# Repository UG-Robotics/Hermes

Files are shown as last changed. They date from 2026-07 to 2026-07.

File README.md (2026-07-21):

# HERMES - WRO 2026 Future Engineers 

Hermes is an autonomous 1:X model car built for the **World Robot Olympiad
2026 Future Engineers** self-driving challenge. It completes both events on the
3m × 3m field — the **Open Challenge** (three laps of a randomised-wall track)
and the **Obstacle Challenge** (three laps obeying red/green traffic signs, then
a parallel park) — under a single start button, with no human input after the
press.

This repository is the complete engineering record: mechanical CAD
(`models/`), electronics and wiring (`schemes/`, `components/`), the full
robot software (`src/`), and supporting media (`v-photos/`, `t-photos/`,
`video/`). The detailed build write-up is in
[`HERMES_TechnicalDocument_WRO2026.pdf`](HERMES_TechnicalDocument_WRO2026.pdf).

---

## How it works at a glance

Hermes uses a **two-tier compute** split, connected by one UART link:

| Tier | Board | Responsibility |
|---|---|---|
| **High-level autonomy** | Raspberry Pi 4 | camera vision, state machine, planning, control decisions |
| **Low-level real-time** | ESP32 | motor + steering-servo PWM, IMU + dual ToF sensing, start button, telemetry |

The Pi never touches a sensor register directly — every IMU/ToF value arrives
as a telemetry packet from the ESP32, and every drive decision leaves as a
command packet. That clean boundary is what lets the **entire stack run on a
laptop with no robot attached** (simulated ESP32 + synthetic camera) for
development and testing.

**Core hardware:** Raspberry Pi 4 · ESP32 · Pi Camera · LSM6DSO 6-axis IMU ·
2× VL53L1X time-of-flight sensors · N20 gear-motor with L298N driver ·
steering servo (Ackermann) · 18650 Li-ion pack + buck converter. See
[`components/`](components/) and [`schemes/`](schemes/) for parts and wiring.

---

## Challenge strategy

### One button, two challenges (auto-detection)

WRO rules allow only **one** start button, so Hermes can't be *told* which
challenge it's running — it works it out itself. The insight: a **red/green
traffic-sign pillar is unique to the Obstacle Challenge**.

- See a pillar → latch **Obstacle** mode (drive the pass-side + parking logic).
- Complete a **full lap with no pillar** → latch **Open** mode (drop pillar
  perception, bias toward the inner wall, finish by lap count).

### Open Challenge

Drive three laps of the corridor using **camera-based wall centering** trimmed
by an **IMU heading-hold PID**, counting the four orange/blue corner markers per
lap. The colour of the *first* corner marker latches the run **direction**;
Hermes then biases its racing line toward the **inner wall** for a tighter,
safer line. After the third lap it clears the finish line and stops.

### Obstacle Challenge

Same lap-following, plus: each red/green pillar raises an avoidance turn —
**pass right of red, left of green** — executed as a smooth IMU-held heading
change, and capped by the side ToF sensors so clearing a pillar never means
clipping a wall. After three laps it hunts the **magenta parking lot** and runs
a staged **parallel-parking** maneuver.

The full behaviour is a priority-driven state machine
(`INIT → WAIT_FOR_START → FOLLOW_TRACK ⇄ AVOID_OBSTACLE / LAP_CHECK →
FINAL_APPROACH → PARK → STOP`, with `ERROR` fail-safe). Diagram and spec:
[`other/State_Transition_Diagram.png`](other/State_Transition_Diagram.png),
[`other/State_Machine_Spec.pdf`](other/State_Machine_Spec.pdf).

---

## Running the software

All commands run from `src/`. The control loop and simulation need only the
**standard library**; the extras below unlock hardware, the dashboard, and
vision.

```bash
pip install -r requirements.txt      # flask, pyserial, pynput, pillow, numpy
pip install opencv-python            # required for real camera perception

python main.py --mode sim --auto-start   # full stack vs simulated hardware, no robot
python main.py --mode dashboard          # live web UI (telemetry + camera + manual drive)
python main.py --mode test               # unit + integration test suite
python main.py --mode run                # REAL hardware (Pi + ESP32) — the competition entry
```

Manual driving is always available (keyboard `w/a/s/d`, space, `m` to toggle, or
the dashboard controls) as an override. Firmware for the ESP32 lives in
[`src/firmware/esp_controller/`](src/firmware/esp_controller/) (Arduino).

---

## Tuning for competition day

The software is written so that going from "runs" to "wins" is **only constant
tuning** — no code changes. Every threshold, gain, colour range, and maneuver
timing is centralised in [`src/config/`](src/config/), and the step-by-step
on-mat procedure (servo trim, IMU sign, PID, HSV colours, ToF safety, parking
timings, …) is documented in **[`src/CALIBRATION.md`](src/CALIBRATION.md)**.

---

## Repository map

| Path | Contents |
|---|---|
| [`src/`](src/) | All robot software — see [`src/README.md`](src/README.md) for the module-by-module breakdown |
| [`src/config/`](src/config/) | Every tunable constant (camera, PID, thresholds, parking, robot) |
| [`src/firmware/`](src/firmware/) | ESP32 real-time controller firmware |
| [`models/`](models/) | Mechanical CAD (chassis, steering, drivetrain) |
| [`schemes/`](schemes/) | Wiring diagrams and electronics schematics |
| [`components/`](components/) | Bill of materials, datasheets, part photos |
| [`v-photos/`](v-photos/) · [`t-photos/`](t-photos/) | Vehicle and team photos |
| [`video/`](video/) | Performance video links ([`video/README.md`](video/README.md)) |
| [`other/`](other/) | State-machine spec and diagrams |

---

## Software architecture

Layered robotics stack, one direction of data flow, each layer independently
testable:

```
PERCEPTION  →  EVENTS  →  STATE MACHINE  →  PLANNING  →  CONTROL  →  COMMUNICATION  →  ESP32
 (camera)     (typed,     (priority        (lane /      (heading-    (UART packets)    (motor +
              prioritised) transitions)     obstacle /   hold PID +                     servo +
                                            parking)     slew)                          sensors)
```

Perception detects, planning decides, control stabilises, communication
transmits — no layer reaches across another. A live **monitoring dashboard**
(`src/monitoring/`) mirrors the same telemetry the robot runs on, so a run
produces a complete, replayable narrative of every decision. Full rationale and
per-module docs: [`src/README.md`](src/README.md).

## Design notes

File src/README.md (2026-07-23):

# `src/` - Robot Runtime Software

## Overview

This directory contains the complete runtime software stack for the autonomous vehicle used in the WRO Future Engineers competition.

The purpose of this folder is to organize all software required for:

* autonomous navigation
* perception and obstacle detection
* decision-making
* motion planning
* low-level control
* communication with embedded hardware

This directory intentionally contains ONLY software directly related to the operation of the physical robot during runtime.

In practice, that includes the live monitoring dashboard, state-machine logic, testing assets, and the embedded controller firmware alongside the main autonomy loop.

The following are intentionally kept out of the runtime path:

* CAD files
* documentation assets (kept in the repo-root folders)
* temporary experiments

Development-only tooling that *does* live under `src/` is clearly separated
from the runtime stack: `simulation/` (Gazebo world + MATLAB vision notes) and
`testing/` are for the bench, not the competition loop, and nothing in the
autonomy path imports them.

---

# High-Level System Architecture

The software stack follows a layered robotics architecture:

```text
PERCEPTION
    ↓
EVENT GENERATION
    ↓
STATE MACHINE / DECISION LOGIC
    ↓
MOTION PLANNING
    ↓
CONTROL
    ↓
COMMUNICATION
    ↓
MCU → MOTOR + SERVO ACTUATION
```

The Raspberry Pi acts as the high-level autonomy computer:

* computer vision
* state transitions
* planning
* decision-making

The ESP32 acts as the low-level controller:

* PWM generation
* steering actuation
* motor actuation
* real-time control loops

---

# Directory Structure

```text
src/
│
├── main.py                 # CLI entry point / mode dispatcher
├── runtime.py              # the orchestrator: the 20 Hz control loop
│
├── perception/
├── state_machine/
├── planning/
├── control/
├── communication/
├── hardware/
├── monitoring/
├── testing/
├── firmware/
├── simulation/             # Gazebo / MATLAB assets (dev only, not runtime)
├── utils/
└── config/
```

---

# Entry Point

## `main.py`

The thin command-line front door. It parses `--mode` and hardware flags
(`--real` / `--sim`) and hands off to the right runner:

* `run` — real hardware, the competition entry point (default)
* `sim` — the same loop against a simulated ESP32 + synthetic camera
* `dashboard` — launch the live monitoring web UI
* `scenario` — replay a scripted event scenario headless
* `test` — run the unittest suite

`main.py` holds no business logic — it only wires up a `Runtime` (or a
scenario/test runner) and starts it.

## `runtime.py`

The actual orchestrator. `Runtime` builds every subsystem (real or simulated),
then runs one control cycle per tick at ~20 Hz:

```text
ingest ESP32 telemetry (IMU / ToF)      ← _drain_incoming
    ↓
perceive (camera → pillar/lane/corner/parking events)   ← _update_vision
    ↓
update state machine (drain queued events)   ← _drain_events
    ↓
decide drive intent (state → speed/steer/action)   ← _resolve_command
    ↓
IMU heading-hold PID correction
    ↓
send CMD packet to ESP32
    ↓
publish a telemetry snapshot for the dashboard
```

It is also where run-level behaviour lives that isn't any single subsystem's
job: challenge auto-detection (OPEN vs OBSTACLE), lap counting, the start
delay, the open-run finish timer, and driving the parking maneuver. Keep
per-subsystem logic in the modules below; `runtime.py` only coordinates them.

---

# Module Descriptions

---

# `perception/`

Responsible for environmental understanding and sensor interpretation.

This module processes camera and sensor data to generate meaningful observations for the rest of the system.

## Responsibilities

* image acquisition
* preprocessing
* ROI extraction
* track detection
* wall detection
* obstacle detection
* pillar color classification
* finish zone detection

## Example Files

```text
perception/
├── camera.py            # real (Picamera2/OpenCV) + synthetic frame source
├── preprocessing.py     # thin compatibility wrapper over pillar detection
├── roi.py               # region-of-interest crop helpers
├── pillar_detection.py  # red/green traffic-sign pillars + pass-side
├── corner_detection.py  # orange/blue corner markers → lap + direction
└── finish_detection.py  # magenta parking-zone marker
```

## Notes

This module should NOT:

* control motors
* make navigation decisions
* contain PID logic

It only answers:

> “What does the robot currently observe?”

---

# `state_machine/`

Responsible for robot behavioural logic.

This module determines:

* what state the robot is currently in
* when state transitions occur
* how events are prioritized

## Responsibilities

* state tracking
* transition logic
* event handling
* state priority management
* fail-safe behaviour

## Example Files

```text
state_machine/
├── states.py         # the State enum
├── transitions.py    # (state, event) → next state table
├── events.py         # EventType enum + priority map + Event/make_event
├── priorities.py     # Priority levels
├── event_queue.py    # thread-safe priority queue (drain per tick)
├── robot_context.py  # shared run state (laps, direction, challenge_mode, …)
└── manager.py        # applies events, gates INIT on camera/serial readiness
```

## Example States

```text
INIT
WAIT_FOR_START
FOLLOW_TRACK
AVOID_OBSTACLE
LAP_CHECK
FINAL_APPROACH
PARK
STOP
ERROR
```

## Notes

The state machine should only manage behaviour and transitions.

It should NOT:

* process raw camera frames
* directly generate PWM signals

---

# `monitoring/`

Responsible for the live dashboard, scenario runner, and telemetry visualization used during development and testing.

This module mirrors the same telemetry stream used by the robot runtime, so the dashboard and the headless scenario runner always show the current system state.

## Responsibilities

* dashboard UI
* scenario simulation
* telemetry visualization
* manual control hooks
* live log display

## Example Files

```text
monitoring/
├── dashboard.py
├── scenario.py
├── __init__.py
├── scenarios/
└── templates/
```

## Notes

The full module documentation lives in `monitoring/README.md`.

---

# `testing/`

Responsible for automated regression tests and mock event helpers.

This folder keeps verification assets separate from the runtime stack while still documenting the expected behaviour of the major software subsystems.

## Responsibilities

* unit tests
* protocol validation
* state-machine regression coverage
* robot-context checks
* mock event generation

## Example Files

```text
testing/
├── test_drive_command.py
├── test_event_queue.py
├── test_protocol.py
├── test_robot_context.py
├── test_transitions.py
└── mock_events.py
```

---

# `firmware/esp_controller/`

Responsible for the microcontroller firmware that executes low-level motor, servo, and telemetry tasks.

This firmware acts as the bridge between high-level autonomy code and the physical actuators on the robot.

## Responsibilities

* serial protocol handling
* motor control
* servo control
* telemetry reporting
* embedded configuration

## Example Files

```text
firmware/esp_controller/
├── esp_controller.ino
├── config.h
├── motor.cpp
├── motor.h
├── servo_control.cpp
├── servo_control.h
├── serial_protocol.cpp
├── serial_protocol.h
├── telemetry.cpp
├── telemetry.h
└── robot_data.h
```

---

# `planning/`

Responsible for motion-level decision making.

This layer transforms behavioural goals into motion targets.

## Responsibilities

* corridor centering (ToF + IMU)
* obstacle-side planning
* steering target generation
* parking trajectory generation
* path adjustment

## Example Files

```text
planning/
├── wall_centering.py    # ToF-based corridor centering (replaces camera lane centering)
├── obstacle_planner.py
├── trajectory.py
└── parking_planner.py
```

## Notes

This layer answers:

> “Where should the robot move next?”

---

# `control/`

Responsible for low-level motion stabilization and command generation.

This module converts motion targets into stable control outputs.

## Responsibilities

* PID control
* steering smoothing
* speed regulation
* filtering
* actuator command generation

## Example Files

```text
control/
├── pid.py
├── steering_control.py
├── speed_controller.py
└── filters.py
```

## Notes

This module should NOT:

* perform computer vision
* make strategic decisions

It answers:

> “How do we physically achieve the desired motion?”

---

# `communication/`

Responsible for Raspberry Pi ↔ MCU communication.

This layer abstracts the serial communication protocol between the high-level computer and the embedded controller.

## Responsibilities

* serial communication
* packet encoding
* packet decoding
* command validation
* timeout handling

## Example Files

```text
communication/
├── serial_link.py
├── protocol.py
└── packet_parser.py
```

## Wire Protocol

Every line is a self-identifying, comma-delimited packet (see
`protocol.py` / `packet_parser.py`).

Pi → ESP32:

```text
CMD,<speed>,<steer>,<ACTION>,<mode>   e.g. CMD,150,-12,FORWARD,0
EMG,<mode>                            emergency stop (bypasses CMD parsing)
PING                                  liveness check
```

ESP32 → Pi:

```text
TEL,ax,ay,az,gx,gy,gz,tof1_mm,tof2_mm   sensor telemetry (~20 Hz)
STATUS,<message>                        boot / error text
EVT,<name>                              hardware event, e.g. START_BUTTON_PRESSED
ACK[,tag]                               acknowledgement
```

## Notes

Communication failures should trigger safe fail-state behaviour.

---

# `hardware/`

Responsible for hardware abstraction and sensor interfaces.

This layer isolates hardware-specific implementations from higher-level logic.

## Responsibilities

* IMU interface
* TOF sensor interface
* button input handling
* diagnostics
* hardware initialization

## Example Files

```text
hardware/
├── imu.py
├── tof.py
├── buttons.py
└── diagnostics.py
```

## Notes

This layer should expose clean interfaces to the rest of the system.

Higher-level modules should not depend on raw hardware implementation details.

---

# `utils/`

Contains reusable helper utilities used across the project.

## Responsibilities

* logging
* timers
* debugging utilities
* math helper functions
* common reusable helpers

## Example Files

```text
utils/
├── logger.py
├── timers.py
├── math_utils.py
└── debug.py
```

---
#`utils/logger.py`
# Logging System

## Purpose

The logging system provides a consistent way for every subsystem of the robot to report information, warnings, errors, and debugging information during development, simulation, and competition runs.

Examples of information that should be logged include:

* State transitions
* Sensor readings
* Obstacle detections
* Lap completions
* Parking events
* Communication failures
* Runtime errors
* Emergency stops

Using a centralized logger makes debugging significantly easier because all messages follow the same format and can be traced back to their originating module.

---

## Logger Location

```text
src/
└── utils/
    └── logger.py
```

---

## Implementation

The logger utility exposes a single function:

```python
from utils.logger import get_logger
```

Example implementation:

```python
logger = get_logger(__name__)
```

The `__name__` parameter automatically identifies the module generating log messages.

For example:

```python
logger = get_logger(__name__)
```

inside:

```text
state_machine/robot_context.py
```

will produce messages such as:

```text
[INFO] state_machine.robot_context: Lap completed. Current lap count = 1
```

---

## Log Levels

### INFO

Used for normal system operation.

Examples:

```python
logger.info("Lap completed.")
logger.info("State transition: INIT -> FOLLOW_TRACK")
```

Output:

```text
[INFO] state_machine.robot_context: Lap completed.
```

---

### WARNING

Used for unusual but recoverable situations.

Examples:

```python
logger.warning("TOF reading appears noisy.")
logger.warning("RobotContext reset.")
```

Output:

```text
[WARNING] state_machine.robot_context: RobotContext reset.
```

---

### ERROR

Used when a subsystem encounters a problem.

Examples:

```python
logger.error("Camera initialization failed.")
logger.error("Robot Error: Camera Failure")
```

Output:

```text
[ERROR] state_machine.robot_context: Robot Error: Camera Failure
```

---

## Usage Rules

Every new module should create its own logger instance.

Example:

```python
from utils.logger import get_logger

logger = get_logger(__name__)
```

Recommended locations:

```text
communication/
control/
hardware/
perception/
planning/
simulation/
state_machine/
```

Do NOT create custom logging implementations in individual modules.

All logging should go through `utils.logger`.

---

## Good Logging Examples

State machine:

```python
logger.info(
    f"State transition: {old_state} -> {new_state}"
)
```

Obstacle detection:

```python
logger.info(
    f"Red pillar detected at x={pillar_x}"
)
```

Communication:

```python
logger.warning(
    "Serial packet dropped."
)
```

Error handling:

```python
logger.error(
    "Camera disconnected."
)
```

---

## Bad Logging Examples

Avoid:

```python
print("something happened")
```

Use:

```python
logger.info("Something happened.")
```

This ensures consistent formatting across the entire project.

---

# `config/`

Contains all configurable runtime parameters.

Centralizing parameters improves:

* maintainability
* tuning
* testing
* reproducibility

## Responsibilities

* PID constants
* camera thresholds
* steering limits
* robot dimensions
* sensor thresholds

## Example Files

```text
config/
├── pid_config.py       # heading-hold PID gains + servo slew
├── thresholds.py       # lane/ToF/speed/lap/challenge/start-delay constants
├── camera_config.py    # resolution + HSV colour ranges + blob/distance
├── parking_config.py   # parallel-parking maneuver timings + geometry
└── robot_config.py     # serial, speeds, steering limits, pins, keymap
```

## Notes

Magic numbers should NEVER be hardcoded throughout the codebase.

Configuration values should be stored here whenever possible.

The full on-mat tuning procedure for these constants lives in
[`CALIBRATION.md`](CALIBRATION.md).

---

# Design Philosophy

The software architecture follows several engineering principles:

## 1. Separation of Concerns

Each module has a single clear responsibility.

Examples:

* perception detects
* planning decides
* control stabilizes
* communication transmits

This prevents tightly coupled “spaghetti code”.

---

## 2. Modularity

Modules should be independently testable and replaceable.

For example:

* obstacle detection can be improved without rewriting the state machine
* PID tuning can change without affecting perception

---

## 3. Deterministic Behaviour

The system prioritizes:

* reliability
* repeatability
* explainability

The architecture is intentionally designed around deterministic robotics principles rather than heavy machine learning pipelines.

---

## 4. Safety and Fail-Safe Design

Critical failures should immediately trigger:

* motor stop
* transition to ERROR state
* safe shutdown behaviour

Examples:

* camera disconnect
* serial timeout
* invalid sensor data

---

# Coding Guidelines

## General Rules

* Keep functions small and focused
* Avoid giant monolithic files
* Prefer readability over cleverness
* Use descriptive variable names
* Document assumptions clearly

---

## File Responsibilities

A file should ideally answer ONE question.

Bad example:

```text
vision_and_pid_and_serial.py
```

Good examples:

```text
pillar_detection.py
serial_link.py
pid.py
```

---

## Logging

Important events should be logged:

* state transitions
* obstacle detections
* communication failures
* lap completion

This improves debugging and post-run analysis.

---

# Runtime Flow Summary

The expected runtime execution order is:

```text
1. Initialize systems
2. Wait for official start
3. Begin track following
4. Detect and avoid obstacles
5. Count laps
6. Return to final section
7. Park / stop
8. Enter safe idle state
```

---

# Intended Audience

This folder structure and architecture are designed to be understandable by:

* judges
* teammates
* future contributors
* reviewers
* maintainers

The project prioritizes:

* clarity
* robustness
* maintainability
* engineering discipline

over unnecessary complexity.

---
<!-- 
# Future Extensions

Potential future improvements may include:

* sensor fusion
* advanced trajectory planning
* adaptive PID tuning
* lightweight ML-assisted perception
* telemetry logging
* improved simulation integration -->

The current architecture is intentionally designed to support future expansion without major restructuring.

---

# Final Notes

This software architecture represents a deliberate engineering decision to prioritize:

* deterministic behaviour
* modularity
* reliability
* maintainability
* competition robustness

The architecture is structured to allow incremental development, independent subsystem testing, and clear separation between perception, decision-making, and control.

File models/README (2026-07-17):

# Models

This folder contains CAD assets for the robot. The table below is intentionally incomplete and can be expanded later.

| model_picture | file | description |
| --- | --- | --- |
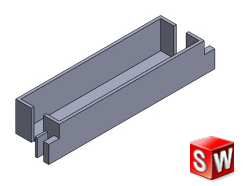
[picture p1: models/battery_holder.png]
battery holder
|  | [battery_holder.STEP](battery_holder.STEP) | Battery holder part. |
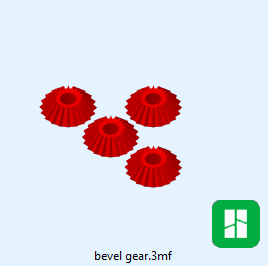
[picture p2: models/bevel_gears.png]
bevel gears
|  | [bevel gear.STEP](bevel%20gear.STEP) | Bevel gear for the drivetrain. |
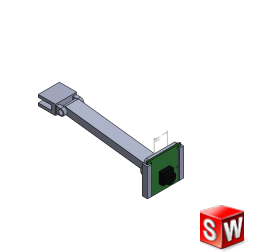
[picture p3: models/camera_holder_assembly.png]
camera holder assembly
|  | [Camera setup]() | Camera holder assembly preview. |
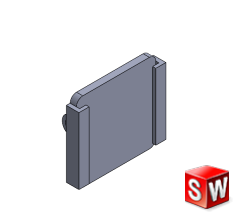
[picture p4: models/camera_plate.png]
camera plate
|  | [camera plate](camera_plate.png) | Camera plate preview. |
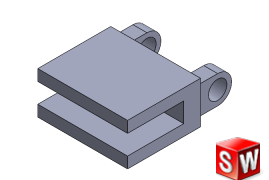
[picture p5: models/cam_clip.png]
camera clip
|  | [camera clip](cam_clip.STEP) | Camera clip preview. |
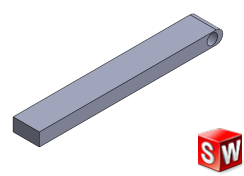
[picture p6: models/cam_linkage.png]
camera linkage
|  | [linkage.STEP](linkage.STEP) | Camera linkage preview. |
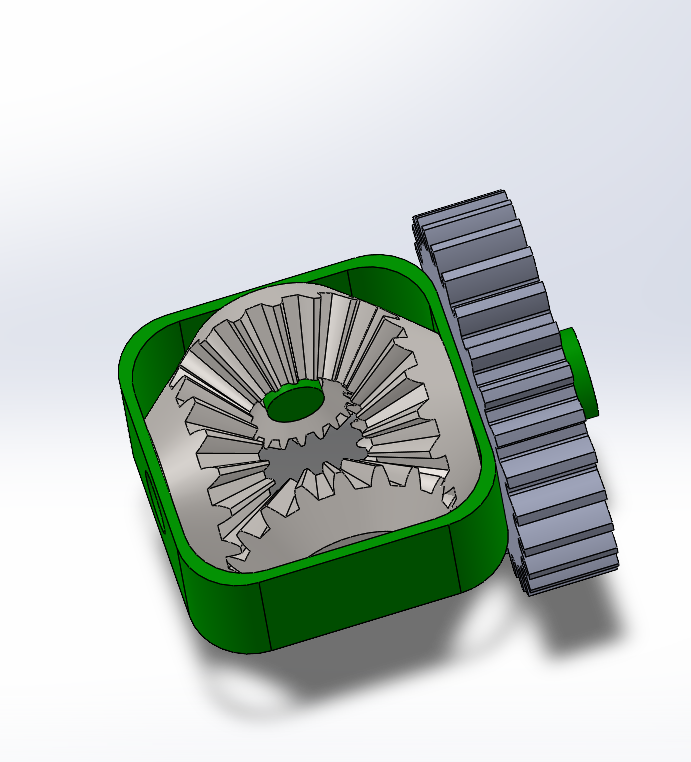
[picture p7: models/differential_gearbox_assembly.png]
differential gearbox assembly
|  | [nDifferential_gearbox.STL](nDifferential_gearbox.STL) | Differential gearbox assembly. |
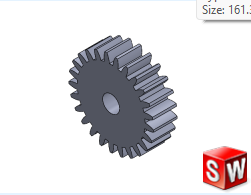
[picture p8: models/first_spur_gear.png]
first spur gear
|  | [first_spur.STEP](first_spur.STEP) | First spur gear. |
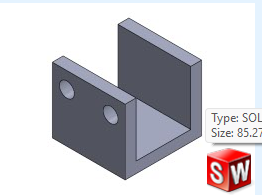
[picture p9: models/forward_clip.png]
forward clip
|  | [Forward Clip](forward_clip.STEP) | Forward clip preview. |
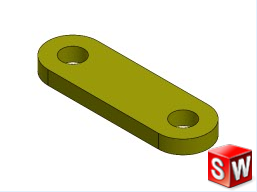
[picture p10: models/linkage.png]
linkage
|  | [linkage.STEP](linkage.STEP) | Main linkage part. |
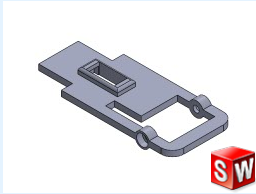
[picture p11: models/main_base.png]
main base
|  | [main_base.STEP](main_base.STEP) | Main base structure. |
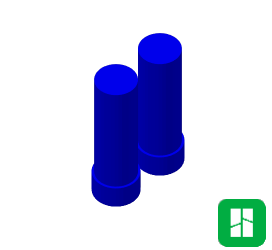
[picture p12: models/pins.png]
pins
|  | [pin.STL](pin.STL) | Pin set preview. |
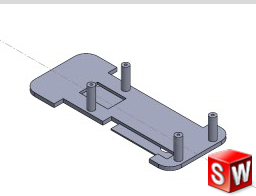
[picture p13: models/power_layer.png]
power layer
|  | [power_layer.STEP](power_layer.STEP) | Power layer assembly. |
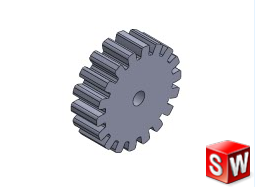
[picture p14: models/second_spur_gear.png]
second spur gear
|  | [second_spur_gear.STEP](second_spur_gear.STEP) | Second spur gear. |
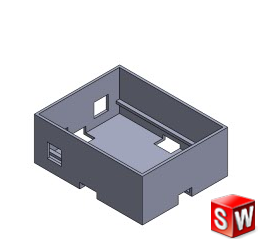
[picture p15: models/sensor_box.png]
sensor box
|  | [Sensor Box](sensor_box.SLDPRT)| Sensor box preview. |
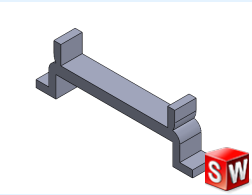
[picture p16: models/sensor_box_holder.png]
sensor box holder
|  | [sensor box holder](sensor_box_holder.SLDPRT) | Sensor box holder preview. |
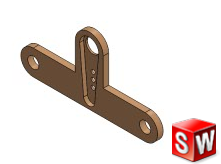
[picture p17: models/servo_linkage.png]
servo linkage
|  | [servo_linkage.STEP](servo_linkage.STEP) | Servo linkage part. |
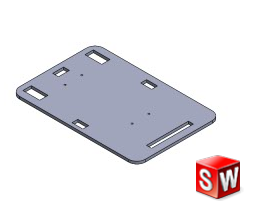
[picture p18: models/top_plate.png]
top plate
|  | [Top Layer](top_layer.STEP) | Top plate preview. |
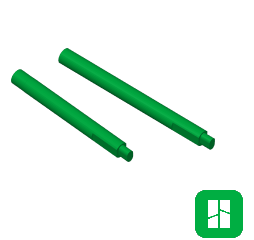
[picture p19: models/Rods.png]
|  | [Rod](rod_actual.SLDPRT) | Top plate preview. |
## Notes

- More models can be added here as the CAD library is finalized.

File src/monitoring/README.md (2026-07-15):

# `monitoring/` — Dashboard & Simulation

A single web page to watch and drive the whole robot, plus a scenario runner for
scripted simulations. Everything here reads from the **TelemetryHub**
(`utils/telemetry_hub.py`), so it shows the exact same data whether the robot is
running on real hardware or fully simulated.

## Quick start

```bash
cd src

# 1. Live monitoring dashboard, fully simulated (no robot needed):
python main.py --mode dashboard
#   → open http://<this-machine>:5000

# 2. Same, but driving REAL hardware from the browser:
python main.py --mode dashboard --real

# 3. Headless simulation of a scripted scenario (prints the captured log):
python main.py --mode scenario --scenario full_match
```

Dependencies for the dashboard: `pip install -r ../requirements.txt` (Flask +
Pillow). The control loop and scenarios run on the standard library alone.

## What the dashboard shows

| Panel | Source channel | Notes |
|---|---|---|
| Camera | `camera.mjpg` | Pi Camera / webcam if present, else a synthetic drawn corridor |
| IMU (ax…gz) | `telemetry` | live 6-axis, real or simulated |
| ToF (left/right) | `telemetry` | dual distance sensors |
| State + Action/Speed/Steer/Lap | `status` | current state-machine state |
| Manual Driving | `POST /api/manual` | on-screen pad + in-browser w/s/a/d keys |
| Inject Events | `POST /api/event` | fire any state-machine event by hand |
| Scenario Simulation | `POST /api/scenarios` | run a scripted event string |
| Pi ⇄ ESP32 Serial | `comms` | live TX/RX packets crossing the link |
| Live Log | `log` | every `logger.*` call in the whole codebase |

## Scenarios ("string events together")

A scenario is a JSON file in `scenarios/` listing timed events:

```json
{
  "name": "obstacle_avoid",
  "description": "Start, dodge a red pillar, resume.",
  "events": [
    {"at": 0.5, "event": "START_BUTTON_PRESSED"},
    {"at": 2.0, "event": "PILLAR_DETECTED_RED"},
    {"at": 4.0, "event": "OBSTACLE_CLEARED"}
  ]
}
```

`at` is seconds from the scenario start. Valid event names are the members of
`EventType` in `state_machine/events.py`. Drop a new `.json` in `scenarios/` and
it appears in the dashboard dropdown automatically.

Run one from the dashboard (dropdown → **Run Scenario**), or headless:

```bash
python main.py --mode scenario --scenario obstacle_avoid
```

## HTTP API

| Method | Path | Body | Purpose |
|---|---|---|---|
| GET | `/api/snapshot` | — | latest value on every channel |
| GET | `/api/logs?limit=200` | — | recent log records |
| GET | `/stream` | — | SSE stream of all channels |
| GET | `/camera.mjpg` | — | MJPEG camera feed |
| POST | `/api/event` | `{"event": "LAP_MARKER_DETECTED"}` | inject an event |
| POST | `/api/manual` | `{"active": true, "target": {"speed":150,"steer":-45,"action":"FORWARD"}}` | manual drive |
| GET/POST | `/api/scenarios` | `{"action":"run","scenario":"full_match"}` | list / run / cancel |

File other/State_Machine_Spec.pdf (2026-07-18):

PART 1: STATE MACHINE DESIGN
- “What mode is the robot currently in?”
- At any moment, the robot should be in EXACTLY ONE state.
- eg:
- Following track
- Avoiding obstacle
- Parking
- Architecture: PERCEPTION -> EVENTS -> STATE MACHINE -> COMMANDS

Event Table:

EVENT | DESCRIPTION
START_BUTTON_PRESSED | Competition officially starts
PILLAR_RED_DETECTED | Red obstacle found
PILLAR_GREEN_DETECTED | Green obstacle found
OBSTACLE_CLEARED | Obstacle passed successfully
LAP_MARKER_DETECTED | Start section revisited
THREE_LAPS_COMPLETE | Mission complete
FINISH_ZONE_DETECTED | Begin stopping
SENSOR_FAILURE | Enter ERROR

States:
INIT
WAIT_FOR_START
FOLLOW_TRACK (+ obstacle checking) AVOID_OBSTACLE
LAP_CHECK
FINAL_APPROACH
PARK
STOP
ERROR

State Table:

STATE | GOAL | SENSORS | OUTPUT | ENTRY CONDITION | EXIT CONDITION | NEXT STATE (TRANSITION)
INIT | Initialize all systems safely | Camera, IMU, TOF, serial status | System checks, idle motor commands | Robot powered on | All systems initialized successfully | WAIT_FOR_STA RT
WAIT_FOR _START | Wait legally for competition start | Start button | Motors disabled | INIT completed | Start button pressed after judge signal(“Go”) | FOLLOW_TRAC K
FOLLOW_ TRACK | Navigate the track while staying centered and moving in correct direction | Camera, TOF, IMU, Wall detection | Steering, speed commands | Start pressed //OR obstacle completed | Pillar detected //OR lap marker detected //OR finish sequence triggered //OR critical failure | AVOID_OBSTAC LE //OR ERROR //OR PARK
AVOID_OB STACLE | Pass obstacle on correct side based on pillar color | Camera, TOF | Modified steering trajectory | Red or green pillar detected | Obstacle successfully passed | FOLLOW_TRAC K
LAP_CHE CK | Verify and count completed laps | Camera / section detection | Increment lap counter | Lap marker or start section detected | Lap count updated | FOLLOW_TRAC K //OR FINAL_APPROA CH
FINAL_AP PROACH | Return safely to finish/start section after lap completion | Camera | Reduced speed steering control | lap_count == 3 | Finish section detected | PARK //OR STOP

PARK | Stop fully within parking/finish zone | Camera | Fine steering, lower speed | Finish section reached | Vehicle fully stopped within target area | STOP
STOP | Maintain complete stop | watchdog monitoring (maybe) | Zero motor speed | Parking complete //OR finish achieved | N/A | N/A
ERROR | Enter safe fail-state | All diagnostic inputs | Stop Motors | Critical failure detected | Manuel reset only | INIT

INIT
Things happening here:
- initialize camera
- initialize serial
- initialize PID
- initialize variables
- verify sensors connected

WAIT_FOR_START
The rules explicitly require:
- switched on
- waiting state
- start button press

FOLLOW_TRACK
Background Processes Running
- track detection
- wall following
- lane estimation
- obstacle detection
- lap detection

AVOID_OBSTACLE
Logic
- Red pillar -> pass RIGHT
- Green pillar -> pass LEFT

LAP_CHECK
Need:
- cooldown timer
- debounce logic
Otherwise:
- double counting happens

FINAL_APPROACH
Robot should:
- become conservative/safer
- prioritize accuracy over speed

PARK
Parking may:
- be optional
- increase score

STOP
Rules specify:
- robot should clearly stop
- avoid ambiguous movement Possible Triggers
- Camera disconnected
- Serial timeout
- Invalid sensor data
- Fatal software exception

State Priority Ranking

PRIORITY | STATE | REASON
1 | ERROR | Safety and fail-safe override all behaviors
2 | AVOID_OBSTACLE | Competition-critical obstacle rules
3 | FINAL_APPROACH / PARK | Precise mission completion behavior
4 | LAP_CHECK | Important but temporary bookkeeping
5 | FOLLOW_TRACK | Default navigation behavior
- | WAIT_FOR_START | Pre-run state only
- | INIT | Startup initialization only
- | STOP | Terminal state

Event Priority Ranking

PRIORITY | EVENT
1 | CRITICAL_FAILURE
2 | PILLAR_DETECTED

3 | FINISH_ZONE_DETECTED
4 | LAP_MARKER_DETECTED

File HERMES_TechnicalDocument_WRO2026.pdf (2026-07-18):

1 | P a g e

WORLD ROBOTICS OLYMPIAD 2026 TEAM HERMES
TECHNICAL DOCUMENTATION

Table of Contents

### 1. Mobility & Mechanical Design 1.1 Design Objectives

The primary objective of Hermes is to provide a reliable, autonomous vehicle capable of completing the WRO 2026 Future Engineers challenge while remaining fully compliant with all competition regulations. Throughout the mechanical design process, emphasis was placed on reliability, modularity, ease of maintenance, and repeatable performance rather than maximum speed.

The robot was designed to:

- Maintain stable steering during continuous autonomous driving.
- Navigate both straight sections and corners with minimal oscillation.
- Provide sufficient space for all electronic components while remaining within the competition size constraints.
- Allow rapid replacement or adjustment of hardware during testing.
- Support future modifications without requiring a complete chassis redesign.

The design philosophy adopted by the team prioritizes consistency over aggressive performance, since a slower but reliable robot is expected to achieve a higher competition score than a faster but inconsistent one.

### 1.2 Mechanical Configuration

Hermes uses a conventional four-wheel vehicle architecture consisting of:

- Four wheels
- One powered drive axle
- One steering axle
- A rigid chassis supporting all electronic and mechanical components

This configuration satisfies the mechanical requirements specified in the WRO 2026 Future Engineers rules.

The steering system is physically separated from the propulsion system. Steering is achieved using a servo motor that rotates the front wheels through a steering linkage, while propulsion is provided by a

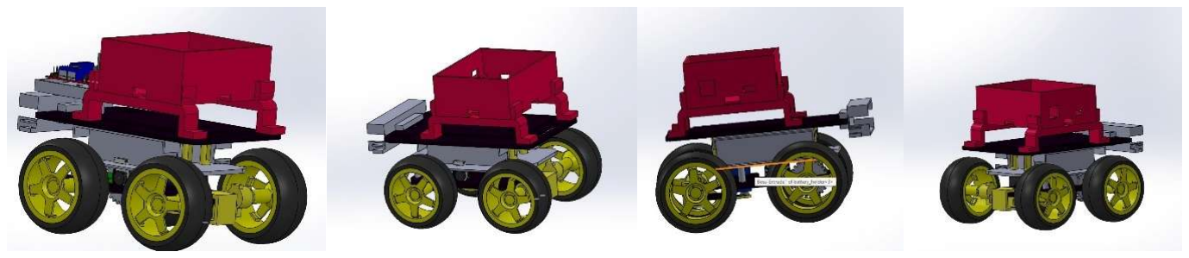
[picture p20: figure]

2 | P a g e

DC motor driving a single axle. Separating steering and propulsion simplifies both the mechanical design and the software control architecture.

The overall chassis was designed to provide:

- Low centre of gravity
- Even weight distribution
- Adequate rigidity
- Easy access to electronics during testing
- Secure mounting locations for sensors and structural components

### 1.3 Chassis Design

The chassis serves as the structural foundation for every subsystem of the robot.

It provides mounting locations for:

- Raspberry Pi 4
- ESP-WROOM-32 microcontroller
- Camera module
- IMU
- Time-of-Flight sensors
- Battery pack
- Steering servo
- Drive motor
- Wiring and power distribution components

The chassis layout was selected to reduce vibration reaching the vision system while also protecting electronics from accidental impact during testing.

Structural rigidity was considered important because excessive chassis flex introduces steering inaccuracies and inconsistent sensor alignment. A rigid frame improves repeatability between runs by maintaining constant sensor positions relative to the vehicle.

Several components are mounted using dedicated brackets or custom 3D-printed parts to simplify maintenance and replacement.

### 1.4 Steering System

Hermes employs an Ackermann-style steering arrangement driven by a single MG90S metal gear servo motor.

This design was selected because it provides:

- Accurate steering angle control

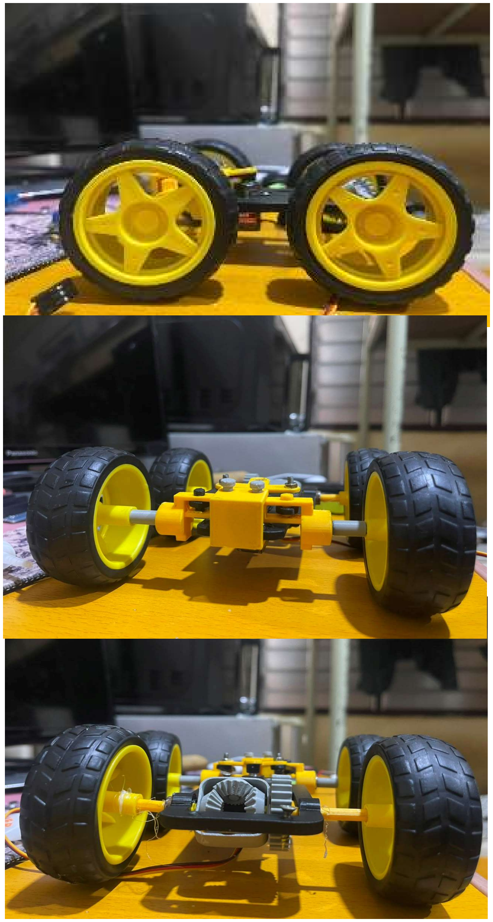
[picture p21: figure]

3 | P a g e
- Fast response time
- Repeatable positioning
- Low mechanical complexity
- Compliance with the single steering actuator rule

Unlike differential steering systems, servo steering allows the robot to maintain smooth trajectories while preserving traction during cornering.

Steering commands are generated by the Raspberry Pi and transmitted to the ESP32, which converts steering requests into servo angles through PWM control.

Using a dedicated steering actuator also simplifies PID tuning since steering angle can be directly controlled rather than indirectly through wheel speed differences.

### 1.5 Drive System

Vehicle propulsion is provided by a single DC motor connected to one drive axle.

The drive system was chosen because it offers:

- Simple control
- High reliability
- Reduced mechanical complexity
- Compliance with WRO regulations requiring a single drive axle

Motor speed is controlled electronically by the ESP32 using PWM signals generated from commands received from the Raspberry Pi.

Separating high-level decision making from low-level motor control reduces latency and allows precise speed regulation without overloading the main processor.

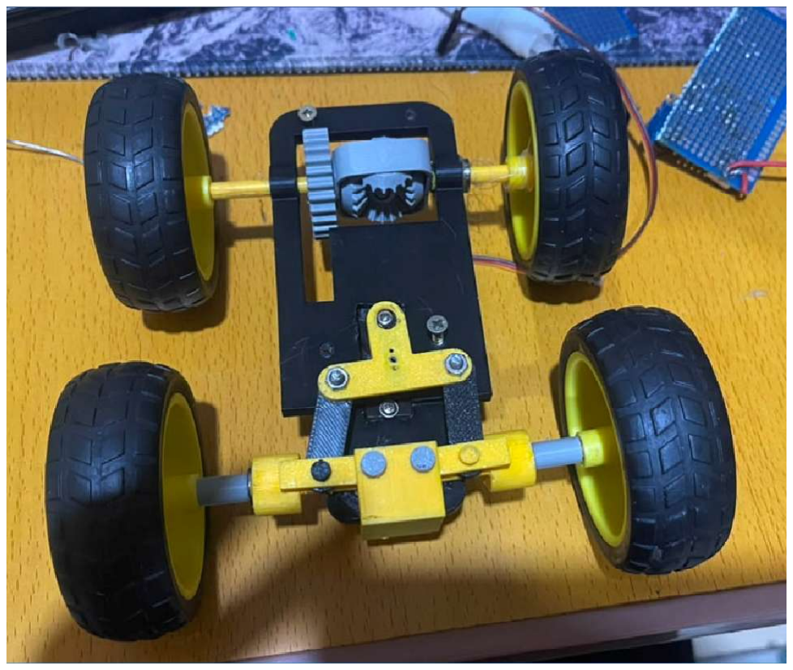
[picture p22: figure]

### 1.6 Wheelbase and Stability

Mechanical stability was considered throughout the chassis design.

A longer wheelbase generally provides:

- Improved straight-line stability
- Reduced steering oscillations

4 | P a g e
- More predictable cornering behaviour

However, increasing wheelbase also increases turning radius.

The final design represents a compromise between:

- Stability
- Turning capability
- Available chassis space
- Competition size constraints

Similarly, the vehicle width was selected to provide adequate lateral stability while remaining comfortably within the maximum allowed dimensions.

### 1.7 Component Mounting Strategy

Sensor placement was carefully considered to maximize measurement accuracy while minimizing interference between subsystems.

The camera is mounted at the front of the vehicle with an unobstructed field of view toward the track.

The IMU is positioned near the centre of mass to reduce rotational measurement errors caused by vibration.

Time-of-Flight sensors are mounted to provide consistent distance measurements relative to surrounding track boundaries.

The battery pack is positioned as low as practical to reduce the centre of gravity and improve stability during cornering.

The Raspberry Pi and ESP32 are mounted securely to minimize vibration while remaining easily accessible for programming and debugging.

### 1.8 Mechanical Design Trade-offs

Several design alternatives were considered before selecting the final configuration.

| Steering Mechanism | Drive Configuration
Alternative | Differential steering using independently driven wheels. | Four-wheel drive.
Rejection Reason | Does not comply with WRO Future Engineers requirements. Produces larger turning radii. Complicates trajectory control. | Increased mechanical complexity. Higher power consumption. Additional drivetrain losses. Not required for the competition environment.
Selected Solution | Single-servo steering with mechanical linkage. | Single powered axle.
Reason | Rule compliant. More accurate steering. Easier to tune using PID control. More predictable vehicle behaviour. | Simpler implementation. Lower current draw. Easier maintenance. Satisfies competition requirements.

Modular Construction

5 | P a g e

Rather than permanently fixing every component to the chassis, the team adopted a modular construction philosophy.

This allows:

- Faster hardware replacement
- Easier debugging
- Sensor repositioning during calibration
- Simplified future upgrades

This approach proved particularly valuable during iterative development, where hardware frequently required adjustment after software modifications.

### 1.9 Mechanical Testing and Iteration

Mechanical development followed an iterative design process.

Each iteration focused on improving one or more of the following:

- Steering accuracy
- Vehicle stability
- Component accessibility
- Structural rigidity
- Sensor alignment
- Reliability during repeated autonomous runs

Changes were validated through repeated testing before being incorporated into the final design.

### 1.10 Compliance with WRO Requirements

The mechanical design was developed specifically to satisfy the WRO 2026 Future Engineers regulations.

Compliance checklist:

- Four-wheel vehicle
- Single drive axle
- Single steering actuator
- Fully autonomous operation
- No wireless communication
- Modular hardware design

### 1.11 Summary

The Hermes mechanical design emphasizes simplicity, reliability, and maintainability. Rather than maximizing speed, the team prioritized repeatable autonomous behaviour through a rigid chassis, servo-based steering, modular construction, and a conventional drive architecture. These decisions simplify both hardware integration and software control while ensuring compliance with the WRO 2026 Future Engineers regulations. Future mechanical refinements will primarily focus on improving durability, steering precision, and ease of maintenance without significantly altering the overall system architecture.

6 | P a g e

### 2. Power & Sensor Architecture 2.1 Design Objectives

The power and sensor architecture of Hermes was designed to provide reliable operation throughout an autonomous run while maintaining a clear separation between high-level perception, low-level control, and power distribution.

The architecture was developed with four primary objectives:

- Provide stable power to all electronic components.
- Ensure sensors receive consistent and reliable measurements.
- Minimize electrical noise affecting perception and control.
- Simplify troubleshooting through modular wiring.

Rather than optimizing for the lowest possible weight or highest possible performance, the team prioritized robustness and ease of maintenance.

### 2.2 System Architecture

Hermes uses a distributed computing architecture consisting of two processing units.

Raspberry Pi 4

The Raspberry Pi serves as the high-level computer responsible for:

- Computer vision
- State machine execution
- Lane following
- Obstacle detection
- Motion planning
- Communication with the ESP32

ESP-WROOM-32

The ESP32 performs all real-time control tasks including:

- Servo control
- Motor speed control
- PWM generation
- Safety monitoring
- Command execution

Separating these responsibilities prevents computationally intensive vision algorithms from affecting real-time motor control.

### 2.3 Power Architecture

The robot is powered using rechargeable lithium-ion batteries arranged as a battery pack.

The power system supplies energy to:

- Raspberry Pi 4
- ESP-WROOM-32
- Steering servo
- Drive motor
- Camera

7 | P a g e
- IMU
- Time-of-Flight sensors

Because these devices operate at different voltage levels and have different current requirements, regulated power conversion is used to ensure stable operation.

A buck converter is used to provide a regulated supply voltage for components requiring lower operating voltages.

This architecture minimizes voltage fluctuations while protecting sensitive electronics from battery voltage variations.

Power Distribution Diagram

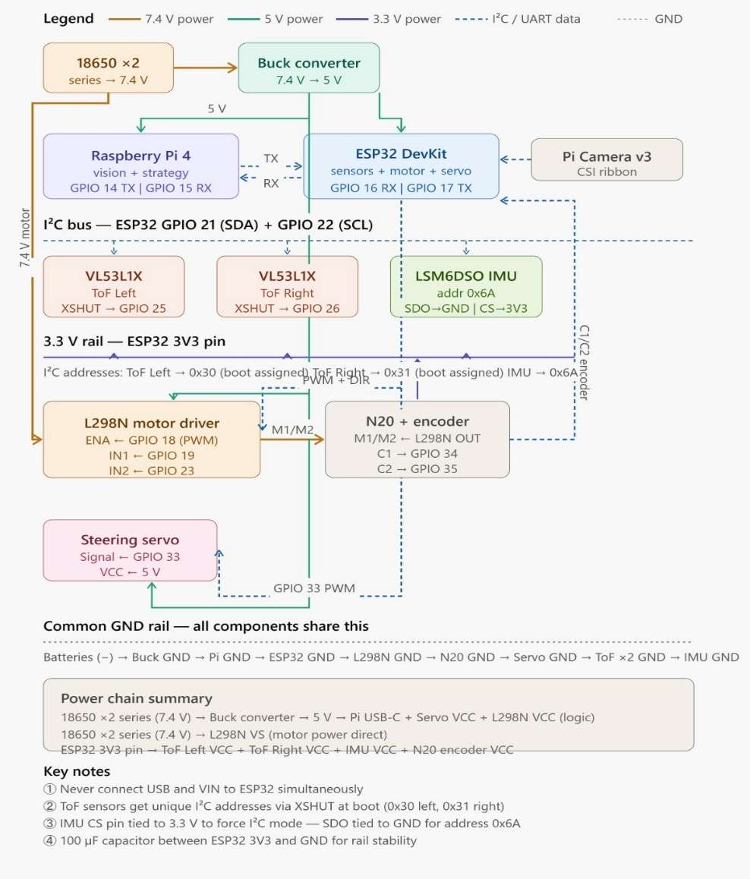
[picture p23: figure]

### 2.4 Battery Selection

Hermes uses lithium-ion 18650 rechargeable cells due to their:

- High energy density
- Rechargeability
- Wide availability
- Stable discharge characteristics
- Good capacity-to-weight ratio

The battery pack was selected to provide sufficient operating time for:

8 | P a g e
- Practice sessions
- Calibration
- Multiple competition runs

without requiring frequent battery replacement.

Measured Battery Capacity

A 3S Li-ion pack has nominal 11.1 V (3×3.7 V) and fully charged 12.6 V (3×4.2 V). For cell capacities of 2200, 3000, and 3500 mAh, the battery energy is:

- Nominal (11.1 V):
o 2200 mAh: 11.1 V × 2.2 Ah = 24.420 Wh o 3000 mAh: 11.1 V × 3.0 Ah = 33.300 Wh o 3500 mAh: 11.1 V × 3.5 Ah = 38.850 Wh
- Full charge (12.6 V):
o 2200 mAh: 12.6 V × 2.2 Ah = 27.720 Wh o 3000 mAh: 12.6 V × 3.0 Ah = 37.800 Wh o 3500 mAh: 12.6 V × 3.5 Ah = 44.100 Wh

Expected Operating Time

Runtime (hrs) =

Battery Energy (Wh)
Total Power (W)

Using nominal 11.1 V:

- 2200 mAh (24.420 Wh):
o Runtime ≈ 24.420 / 20.600 = 1.186 hr (≈1 h 11 min)
- 3000 mAh (33.300 Wh):
o Runtime ≈ 33.300 / 20.600 = 1.616 hr (≈1 h 37 min)
- 3500 mAh (38.850 Wh):
o Runtime ≈ 38.850 / 20.600 = 1.888 hr (≈1 h 53 min)

### 2.5 Voltage Regulation

Different electronic components require different supply voltages.

Rather than powering every component directly from the battery pack, regulated voltage conversion is used to provide stable operating conditions.

Voltage regulation offers several advantages:

- Improved system stability
- Reduced electrical noise
- Protection against battery voltage variation
- More reliable sensor measurements
- Reduced likelihood of processor resets

Stable voltage regulation is particularly important for the Raspberry Pi and ESP32 because voltage drops can lead to unexpected software failures or system restarts during autonomous operation.

9 | P a g e

### 2.6 Estimated Power Budget

The overall power budget was considered during system design to ensure that the selected battery pack could safely supply every subsystem.

A detailed power budget (Table below) lists each subsystem’s voltage, current, and power. Values are from official sources when available. Notable points: the Raspberry Pi 4 draws ~0.540 A (2.7 W) at idle and up to ~1.280 A (6.4 W) under load [2+L38-L41]. We assume ~0.900 A (4.500 W) as a design point. The ESP32 DevKit typically consumes ~80 mA at 3.3 V [14+L184-L188] (0.264 W); accounting for 5 V logic and USB interface, we assume ~120 mA at 5 V (0.600 W). The Raspberry Pi Camera Module (~1.25 W) needs about 0.250 A from 5 V [16+L179-L187]. Each VL53L1X TOF sensor draws ~19 mA at 3.3 V (0.063 W) [22+L301- L308]. The LSM6DSO IMU in high-performance mode draws ~0.55 mA at 3.3 V [24+L2-L10] (≈0.002 W). A typical 5 V hobby servo (e.g. SG90/MG90) may draw ~0.550–0.750 A at stall [26+L43-L47]; we assume 0.500 A (2.500 W) for sustained load. The L298N driver’s logic supply (~5 V) draws on the order of 30–50 mA [30+L200-L209]. The N20 geared DC motors (running at ≈11.1 V) draw roughly 0.8 A each under load (≈8.880 W)[32+L21-L24][33+L153-L161]; their no-load current is only ~0.04–0.08 A[32+L21-L24] [33+L153-L161]. Encoder and minor GPIO loads are negligible.
Component | Voltage (V) | Current (A) | Power (W)
Raspberry Pi 4 | 5.000 | 0.900 | 4.500
ESP32 DevKit | 5.000 | 0.120 | 0.600
Pi Camera v3 | 5.000 | 0.250 | 1.250
VL53L1X Left | 3.300 | 0.020 | 0.066
VL53L1X Right | 3.300 | 0.020 | 0.066
LSM6DSO IMU | 3.300 | 0.0006 | 0.002
Steering Servo | 5.000 | 0.500 | 2.500

### 2.7 Wiring Strategy

The wiring architecture was designed to reduce clutter while simplifying maintenance and fault diagnosis.

Key principles used include:

- Short signal paths where practical.
- Separation of power wiring from communication wiring.
- Secure mechanical fastening of connectors.
- Modular wiring to simplify component replacement.

Communication between the Raspberry Pi and ESP32 is performed using a dedicated serial connection, allowing high-level motion commands to be transmitted without introducing unnecessary wiring complexity.

Power distribution follows a centralized architecture, with regulated outputs supplying each subsystem independently.

Wiring Diagram (System and ESP)

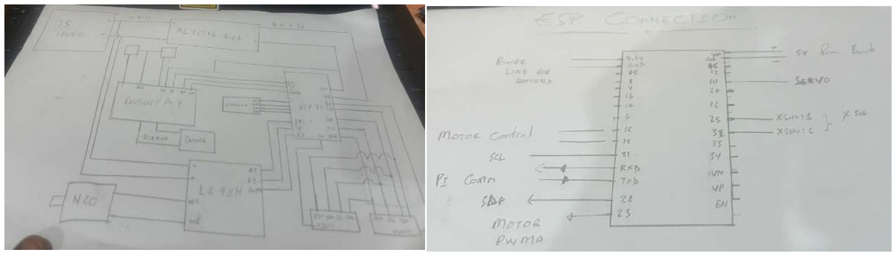
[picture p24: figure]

10 | P a g e

### 2.8 Sensor Selection

Hermes combines multiple complementary sensors to improve robustness during autonomous navigation.

Raspberry Pi Camera Module 3

The camera serves as the primary perception sensor.

It is responsible for:

- Detecting coloured pillars
- Identifying lane boundaries
- Supporting track following
- Detecting finish and parking regions

The camera provides significantly richer environmental information than individual distance sensors and therefore forms the foundation of the perception pipeline.

Inertial Measurement Unit (IMU)

The IMU (LSM6DSOX, 6-axis accel+gyro) is physical hardware wired only to the ESP32's I2C bus, so, the Pi never opens an I2C bus or reads a register itself; the ESP32 streams ax,ay,az,gx,gy,gz up in every TEL packet, and hardware/imu.py only ever reads that already-published value back out of the TelemetryHub. The one computation the Pi does perform is integrating gz (yaw rate) over dt into a running heading estimate - this is a control-layer computation over already-transmitted data, not a hardware read, which is why it lives on the Pi alongside the rest of the decision-making in control/steering_control.py. That heading estimate is the single input to the heading-hold PID: FOLLOW_TRACK locks a target heading once (hold_straight()) and holds it through pure IMU integration by default, AVOID_OBSTACLE locks an offset target via turn_by() when a pillar is detected, and the camera's lane-centering and TOF-based wall-avoidance both work by nudging that same locked target (nudge_target()) rather than issuing their own steering commands - so the IMU heading-hold loop is the single point that actually talks to the servo, and everything else (vision, ToF) only ever adjusts what it's aiming for.

Time-of-Flight Sensors

Two Time-of-Flight sensors are mounted on the robot.

Their intended purpose is to:

- Measure distance to nearby walls
- Improve positioning accuracy
- Provide additional environmental awareness
- Support safe navigation around obstacles

11 | P a g e

Using active distance sensors complements vision by providing direct distance measurements that are less sensitive to lighting conditions.

Both ToF sensors (VL53L0X) are physical hardware wired only to the ESP32, sharing the IMU's I2C bus and re-addressed at boot via the standard XSHUT sequence (VL53L0X has no hardware address-select pin, so the LEFT sensor is initialised alone and moved off the shared default 0x29 before the RIGHT sensor is released from reset). firmware/esp_controller/tof.cpp's readTOF() fills tof1_mm(left)/tof2_mm(right) into the same RobotTelemetry struct the IMU uses, sent up as one TEL packet - there is no separate ToF packet type. On the Pi, hardware/tof.py is a pure pass-through reading the latest published telemetry, with no sensor logic of its own. Integration into decision-making happens entirely in planning/obstacle_planner.py: adjust_avoidance_steer() caps the pillar-avoidance steering angle (and issues a small corrective heading nudge) when the ToF on the side being steered toward reads below a warning/critical distance, and general_speed_scale() derives a 0.5–1.0 speed multiplier from whichever side wall is closest, applied continuously in both FOLLOW_TRACK and AVOID_OBSTACLE. This makes ToF a safety guardrail layered on top of camera-based pillar avoidance, not an independent avoidance system - it cannot change which side a pillar is dodged on, only how far the bot commits to that dodge.

### 2.9 Sensor Placement

Sensor placement was determined according to the geometry of the WRO playing field.

Camera Position

The vision system uses a Raspberry Pi Camera v3 mounted approximately 120 cm above the ground and tilted downward by 20°. This configuration was selected after evaluating the trade-off between field of view, obstacle visibility, and image distortion.

The elevated mounting position increases the visible area in front of the vehicle, allowing the camera to simultaneously observe lane boundaries, wall segments, corner markers, and obstacles at greater distances. A higher viewpoint reduces the likelihood of nearby objects obscuring important navigation features and provides more time for the control algorithm to react to upcoming track elements.

A downward tilt of 20° was chosen to focus the camera on the region most relevant to navigation. With a smaller tilt angle, a significant portion of the image would contain the horizon and background, reducing the number of useful pixels dedicated to the track. Conversely, a much steeper angle would reduce the forward look-ahead distance and make obstacle detection less reliable. The 20° angle provides a balance between near-field visibility and long-range perception.

This configuration offers several advantages:

- Increased look-ahead distance, improving path planning and steering decisions.
- Better obstacle detection, as obstacles remain visible for a longer period before reaching the robot.
- Improved lane recognition, with both track boundaries visible within a single frame.
- Reduced image distortion compared to extreme camera angles.
- More stable computer vision performance, since lighting changes and distant background objects occupy a smaller portion of the image.

As a result, the selected camera position maximizes the amount of useful environmental information available to the vision algorithm while maintaining reliable detection of walls, obstacles, and navigation markers throughout the competition course.

12 | P a g e


IMU Position

The IMU is mounted close to the vehicle's centre of mass.

This minimizes rotational acceleration errors and reduces measurement noise caused by vibration.

TOF Sensor Placement

The Time-of-Flight sensors are positioned to observe nearby track boundaries while minimizing interference from other components.

Their placement was selected to maximize useful distance measurements during normal driving. They were placed on the two sides of the bot.

### 2.10 Sensor Calibration

Reliable autonomous behaviour requires careful sensor calibration before testing.

Camera Calibration

The vision pipeline requires calibration of:

- Colour thresholds
- Exposure
- White balance
- Region-of-interest boundaries

Calibration ensures consistent colour detection under varying lighting conditions.

TOF Calibration

Distance sensors require calibration to verify:

- Detection range: with each sensor un-obstructed, confirm readings stay near TOF_MAX_VALID_MM (2000mm, config/thresholds.py) rather than drifting or reading spuriously short — VL53L0X's usable range is roughly 30–2000mm depending on target reflectivity.
- Distance accuracy: place a flat white target (matching the mat's wall material) at 5-6 known distances spanning the operating range (e.g. 50, 100, 200, 500, 1000mm), log 20+ consecutive readings at each, and compare the mean against the ruler-measured true distance. VL53L0X is typically accurate to a few mm under 200mm, degrading at longer range.
- Measurement consistency: at a single fixed distance, compute the standard deviation across 50+ consecutive samples - this quantifies sensor noise the control loop will need to tolerate (informs whether TOF_WALL_WARNING_MM/TOF_WALL_CRITICAL_MM need a larger safety margin).

13 | P a g e
- Sensor alignment: confirm each sensor's optical axis is perpendicular to the side it's meant to measure - an angled mount reads a false, larger distance to a flat wall, which would make the bot think it has more clearance than it does. Checked by comparing the reading against a physically-measured perpendicular distance at a known wall angle.
- Cross-talk check: with both sensors active, confirm the left sensor's reading doesn't change when only the right sensor's line of sight is obstructed (and vice versa) - relevant because both sensors share one I2C bus and sit close together on a small chassis.

IMU Calibration

IMU calibration is performed automatically on every boot rather than once at the bench: during INIT, before the start button is armed, the ESP32 holds the chassis in a stationary window and samples raw accelerometer and gyroscope output at the telemetry rate, computing the mean of each axis as that boot's bias (with the accelerometer's vertical axis offset from the expected 1g rather than zero). This bias is subtracted from every subsequent sample before it is packed into the TEL packet, so the Pi's heading-hold controller always operates on already-corrected data and requires no calibration logic of its own. Automatic re-calibration on every power-on was chosen over a fixed bench-measured constant because MEMS gyro bias drifts with temperature and mounting stress, and a constant measured once in a lab would not hold at competition conditions. Sign and scale correctness - confirming that a physical clockwise rotation produces a positive, correctly-scaled heading change, matching the "+ = right" convention used throughout the steering stack - is verified separately via a one-time bench turntable test per hardware build, since that property depends on physical wiring and mounting orientation rather than on drift, and does not need to be re-checked every run.

### 2.11 Reliability Considerations

Several potential failure modes were considered during system design.

Voltage Drop

Rapid motor acceleration may temporarily increase current consumption.

Mitigation:

- Regulated power supply
- Adequate battery capacity
- Separate control electronics from high-current devices where practical

Sensor Failure

If a sensor produces invalid data, the software architecture is designed to avoid unsafe behaviour.

Fault | Detection | Handling
ESP32 sensor init failure (IMU or either ToF) | Firmware initIMU()/initTOF() return false; ESP32 sends STATUS,ERR ... | Non-fatal on the firmware side -readIMU()/readTOF() fall back to safe defaults (level/stationary, or OUT_OF_RANGE_MM) rather than garbage values; the Pi never even hears an "OK" for that sensor
ESP32 alive but sensors never confirmed | Serial link up, but no valid TEL packet seen | Runtime._await_first_telemetry() blocks briefly at startup; run_startup_diagnostics() reports sensor status as UNCONFIRMED rather than

14 | P a g e
| | asserting REAL, and StateMachine.__init__ gates INIT → WAIT_FOR_START on camera_ready/serial_ready
Malformed/truncate d TEL packet | communication/packet_pa rser.py checks field count and that every field parses as float | Logs a warning, returns {"type": "unknown"}; the last-known-good telemetry in the hub is left untouched rather than being corrupted
Serial port physically unavailable | SerialLink.connect() exception from pyserial | Degrades to EMULATION mode (TX logged, RX empty) instead of crashing the whole process
No camera hardware | Camera._open_real() exceptions from both Picamera2 and OpenCV | Falls back to SYNTHETIC frames; run_startup_diagnostics() reports this honestly rather than pretending the feed is real
A pillar/corner/parkin g-zone/wall reading vanishes mid-detection | PillarDetector/CornerTrac ker require N consecutive lost frames (hysteresis) before declaring "cleared", instead of one dropped frame flipping state | Prevents a single noisy frame from double-counting a corner or prematurely exiting AVOID_OBSTACLE
Wall gets dangerously close during a pillar-avoidance turn | planning/obstacle_planner .py checks live ToF against TOF_WALL_CRITICAL _MM | Caps the commanded avoidance angle and issues a corrective nudge away from that wall, every tick, independent of the camera
Invalid state transition requested | TransitionManager.get_ne xt_state() has no matching table entry | Logged, current state left unchanged rather than the state machine silently jumping somewhere undefined
Any FAILURE_DETEC TED event, from any state | transitions.py special-cases this event type ahead of the normal lookup table | Unconditionally forces State.ERROR regardless of current state, and Runtime._drain_events() calls self.steering.reset() on entry so no stale PID/target-heading state survives into whatever run follows a manual reset
Uncaught exception anywhere in the tick loop | run_forever()'s top-level try/except Exception | Logged with full traceback, then finally: self.shutdown() fires an EMG (emergency stop) packet before the process exits

Loose Connections

Repeated testing may loosen connectors.

Mitigation strategies include:

- Secure cable routing
- Mechanical strain relief

15 | P a g e
- Modular connectors
- Routine inspection before testing sessions

### 2.12 Design Trade-offs

Several design decisions involved balancing competing engineering priorities.

Camera vs Distance Sensors

Rather than relying exclusively on one sensing technology, Hermes combines vision and distance sensing.

Advantages include:

- Improved robustness
- Complementary measurements
- Reduced sensitivity to individual sensor limitations

Distributed Control

Instead of using a single processor for all tasks, Hermes separates perception and real-time control.

Advantages include:

- Better computational efficiency
- Reduced latency
- Easier software maintenance
- Improved system reliability

Battery Capacity vs Weight

Increasing battery capacity extends operating time but also increases vehicle mass.

The selected battery configuration represents a balance between:

- Competition runtime
- Vehicle weight
- Available installation space

### 2.13 Summary

The power and sensor architecture of Hermes was designed to provide reliable autonomous operation through stable power distribution, modular wiring, and complementary sensing technologies. The Raspberry Pi performs computationally intensive perception and planning tasks, while the ESP-WROOM-32 provides deterministic real-time control of the vehicle. Careful sensor placement, regulated power delivery, and modular system design simplify maintenance while improving overall robustness. Future work will focus on completing sensor calibration, validating the power budget through experimental measurements, and further improving fault tolerance through software-based diagnostics.

### 3. Software Architecture & Obstacle Strategy 3.1 Design Objectives

The Hermes software architecture was designed around the principle of separating high-level autonomous decision-making from low-level hardware control. This separation improves reliability,

16 | P a g e

simplifies debugging, and allows each processor to specialize in tasks that match its computational strengths.

The software architecture was developed with the following objectives:

- Maintain modular and reusable code.
- Ensure deterministic robot behaviour.
- Separate perception from control.
- Allow independent testing of software modules.
- Enable safe recovery from communication or sensor failures.

Rather than relying on complex artificial intelligence techniques, Hermes uses deterministic algorithms that are easier to understand, debug, and reproduce.

### 3.2 Overall Software Architecture

The software is divided between two processing units.

Raspberry Pi

The Raspberry Pi is responsible for all computationally intensive tasks, including:

- Image acquisition
- Computer vision
- Lane detection
- Obstacle detection
- State machine execution
- Motion planning
- Communication with the ESP32

ESP-WROOM-32

The ESP32 performs all real-time hardware control, including:

- Servo control
- Motor speed control
- PWM generation
- Command execution
- Safety watchdog monitoring

This separation ensures that delays in image processing cannot interfere with precise motor control.

### 3.3 Layered Software Design

The Hermes software follows a layered architecture consisting of four logical layers.

Sensor Layer

Collects raw information from:

- Camera
- IMU
- Time-of-Flight sensors

↓

Perception Layer

17 | P a g e

Processes raw sensor data into meaningful information such as:

- Track position
- Pillar colour
- Lane offset
- Finish zone detection

↓

Decision Layer

Determines the appropriate robot behaviour using a finite state machine.

↓

Control Layer

Converts high-level commands into steering angles and motor speeds before transmitting them to the ESP32.

This separation improves maintainability and allows each layer to be tested independently.

### 3.4 Repository Structure

The repository is organized into logical modules that separate responsibilities.

Firmware/
ESP32 firmware responsible for:
- Motor control
- Servo control
- Serial communication
- Safety watchdog
- Hardware interfaces

src/
├── communication/
│ └── Configuration and packet handling.
│
├── config/
│ └── Robot configuration and system parameters.
│
├── control/
│ └── Steering control, speed control, and drive command generation. │
├── hardware/
│ └── Hardware interface modules.
│
├── perception/
│ └── Computer vision and environmental sensing. │
├── planning/
│ └── Navigation and obstacle planning.
│
├── simulation/
│ └── Simulation utilities.
│

18 | P a g e

├── state_machine/
│ └── Finite State Machine implementation. │
├── testing/
│ └── Software testing utilities.
│
├── utils/
│ └── Shared helper functions. │
├── docs/
│ └── Project documentation.
│
└── assets/
| └── Supporting media and design resources.

The modular repository structure improves readability and makes future development easier.

### 3.5 Software Modules

Communication

Responsible for communication between the Raspberry Pi and ESP32.

Responsibilities include:

- Packet formatting
- Command transmission
- Packet parsing
- Communication validation

Commands generated by the Raspberry Pi are transmitted over serial and interpreted by the ESP32 before being converted into motor actions.

Perception

The perception module transforms camera images into information that can be understood by the robot.

Responsibilities include:

- Image acquisition
- Colour segmentation
- Region-of-interest processing
- Contour detection
- Lane estimation
- Pillar detection
- Finish detection

Rather than processing the entire image equally, Regions of Interest (ROIs) are used to reduce computational cost and improve detection speed.

Planning

The planning layer converts perception results into navigation decisions.

Responsibilities include:

- Lane centreing

19 | P a g e
- Obstacle planning
- Parking planning
- Motion target generation

Planning does not directly control motors.

Instead, it determines the desired steering and speed that should be executed by the control layer.

Control

The control module converts planned motion into actuator commands.

Responsibilities include:

- PID steering
- Speed regulation
- Steering smoothing
- Command generation

Outputs are transmitted to the ESP32 through the communication layer.

State Machine

The state machine controls the overall behaviour of the robot.

Instead of allowing every module to make independent decisions, all behaviour is coordinated through a finite set of predefined operating states.

This ensures predictable and reproducible robot behaviour.

### 3.6 State Machine Design

Hermes uses a finite state machine to coordinate every stage of autonomous operation.

At any point during execution, the robot exists in exactly one state.

STATE | GOAL | SENSORS | OUTPUT | ENTRY CONDITION | EXIT CONDITION | NEXT STATE (TRANSITION)
INIT | Initialize all systems safely | Camera, IMU, TOF, serial status | System checks, idle motor commands | Robot powered on | All systems initialized successfully | WAIT_FOR_STA RT
WAIT_FOR _START | Wait legally for competition start | Start button | Motors disabled | INIT completed | Start button pressed after judge signal(“Go”) | FOLLOW_TRA CK
FOLLOW_ TRACK | Navigate the track while staying centered and moving in correct direction | Camera, TOF, IMU, Wall detection | Steering, speed commands | Start pressed //OR obstacle completed | Pillar detected //OR lap marker detected //OR finish sequence triggered //OR critical failure | AVOID_OBSTA CLE //OR ERROR //OR PARK

20 | P a g e
AVOID_OB STACLE | Pass obstacle on correct side based on pillar color | Camera, TOF | Modified steering trajectory | Red or green pillar detected | Obstacle successfully passed | FOLLOW_TRA CK
LAP_CHEC K | Verify and count completed laps | Camera / section detection | Increment lap counter | Lap marker or start section detected | Lap count updated | FOLLOW_TRA CK //OR FINAL_APPRO ACH
FINAL_AP PROACH | Return safely to finish/start section after lap completion | Camera | Reduced speed steering control | lap_count == 3 | Finish section detected | PARK //OR STOP
PARK | Stop fully within parking/finish zone | Camera | Fine steering, lower speed | Finish section reached | Vehicle fully stopped within target area | STOP
STOP | Maintain complete stop | watchdog monitoring (maybe) | Zero motor speed | Parking complete //OR finish achieved | N/A | N/A
ERROR | Enter safe fail-state | All diagnostic inputs | Stop Motors | Critical failure detected | Manuel reset only | INIT

### 3.7 Event-Driven Behaviour

State transitions occur only when specific events are detected.

Examples include:

- START_BUTTON_PRESSED
- PILLAR_RED_DETECTED
- PILLAR_GREEN_DETECTED
- OBSTACLE_CLEARED
- LAP_MARKER_DETECTED
- THREE_LAPS_COMPLETE
- FINISH_ZONE_DETECTED
- SERIAL_TIMEOUT
- SENSOR_FAILURE

Using events rather than continuously changing behaviour prevents unexpected transitions and improves software reliability.

### 3.8 Track Following Strategy

Hermes primarily follows the track using computer vision.

The perception system identifies the track boundaries within predefined Regions of Interest.

These boundaries are used to estimate the robot's lateral position relative to the centre of the lane.

21 | P a g e

An error value is computed representing the offset between the desired position and the measured position.

This error becomes the input to the steering controller.

Using continuous lane estimation provides smoother motion than discrete steering commands.

FRAME_WIDTH := camera.width (px)
center := FRAME_WIDTH // 2

# In a fixed ROI band (LANE_ROI_TOP_FRAC..LANE_ROI_BOTTOM_FRAC of frame height):

# | mask := HSV pixels with V <= LANE_BLACK_V_MAX and S <= LANE_BLACK_S_MAX

# | col_counts[x] := smoothed count of masked pixels in column x

# | min_pixels := roi_height * LANE_MIN_WALL_FRACTION

left_wall_px := nearest x < center where col_counts[x] >= min_pixels, scanning outward from center (or None)
right_wall_px := nearest x > center where col_counts[x] >= min_pixels, scanning outward from center (or None)

if left_wall_px and right_wall_px:
corridor_center := (left_wall_px + right_wall_px) / 2 # confidence = 1.0
elif left_wall_px only:
corridor_center := left_wall_px + LANE_DEFAULT_HALF_WIDTH_PX # confidence = 0.5 elif right_wall_px only:
corridor_center := right_wall_px - LANE_DEFAULT_HALF_WIDTH_PX # confidence = 0.5 else:
lane_offset_px := invalid (no correction applied this frame)

lane_offset_px := clamp(corridor_center - center, ±(FRAME_WIDTH/2 * LANE_MAX_OFFSET_FRAC))

### 3.9 Steering Control

Steering is controlled using a PID controller.

The PID controller continuously minimizes the lane offset error by adjusting the steering angle.

The proportional term provides immediate correction.

The integral term compensates for persistent errors.

The derivative term reduces oscillation by responding to changes in error.

This combination produces smooth steering while reducing overshoot during cornering.

Configured PID gains

Parameter | Value
STEER_PID_KP | 1.6
STEER_PID_KI | 0.02
STEER_PID_KD | 0.35
Output clamp | ±45° (correction authority, not full steering range)
Integral anti-windup clamp | ±20°·s

22 | P a g e
Servo slew limit | 12°/tick at the 20Hz control loop

### 3.10 Speed Control

Vehicle speed is adjusted according to driving conditions.

Examples include:

- Straight sections - Higher speed.
- Sharp turns - Reduced speed to improve stability.
- Obstacle avoidance - Reduced speed to improve positioning accuracy.
- Final approach - Low speed for accurate stopping.

Reducing speed during difficult manoeuvres significantly improves repeatability and reduces the likelihood of leaving the track.

### 3.11 Obstacle Detection

Obstacle detection is performed using the Raspberry Pi Camera Module.

The perception pipeline performs the following operations:

- Capture image
- Apply colour space conversion
- Threshold red and green colours
- Detect contours
- Identify valid pillars
- Estimate pillar position

Detected obstacles are classified according to colour before being passed to the planning module.

Using colour segmentation provides a computationally efficient solution that is well suited to the fixed colours defined by the WRO rules.

### 3.12 Obstacle Strategy

The obstacle strategy follows the WRO Future Engineers competition rules.

When a pillar is detected:

- Red pillar - The robot plans a trajectory that passes on the right side of the pillar.
- Green pillar - The robot plans a trajectory that passes on the left side of the pillar.

Once the obstacle has been safely passed, the robot transitions back to normal lane-following behaviour.

This strategy is implemented using deterministic rules rather than machine learning, making the robot's behaviour easier to verify and reproduce.


23 | P a g e

### 3.13 Communication Protocol

The Raspberry Pi communicates with the ESP32 using a serial communication protocol.

The Raspberry Pi sends high-level commands describing the desired vehicle motion.

The ESP32 parses these commands and generates the required PWM signals for the steering servo and drive motor.

The ESP32 validates incoming packets before execution.

24 | P a g e

Invalid or incomplete packets are ignored to prevent unintended robot movement.

Pi → ESP

Packet | Format
Motion command | CMD,<speed>,<steer>,<action>,<mode>\n
Emergency stop | EMG,<mode>\n
Liveness check | PING\n
Acknowledge | ACK,<tag>\n

ESP→Pi

Packet | Format
Status/log line | STATUS,<message>\n
Telemetry | TEL,<ax>,<ay>,<az>,<gx>,<gy>,<gz>,<tof1_mm>,<tof2_mm>\n
Acknowledge | ACK,<tag>\n
Liveness | PING\n
Hardware event | EVT,<name>\n

All packets are newline-terminated, self-identifying by a leading comma-separated tag (no fixed-width binary framing), and parsing never raises - malformed input degrades to {"type": "unknown"} rather than crashing the read loop.

### 3.14 Safety Mechanisms

Several software mechanisms improve operational safety.

Serial Watchdog

If communication from the Raspberry Pi stops unexpectedly, the ESP32 automatically stops the motor after a predefined timeout.

This prevents uncontrolled motion in the event of processor failure.

Error State

Critical failures such as invalid sensor data or communication loss cause the robot to enter the ERROR state.

In this state:

- Motors stop.
- Steering commands cease.
- The robot waits for manual intervention.

Defensive Programming

Software modules perform input validation before processing data.

Unexpected values are handled safely rather than causing software crashes.

### 3.15 Software Testing

Each software module is designed to be tested independently before full system integration.

Metric | Result

25 | P a g e
Unit test suite (python main.py --mode test) | 69/69 passing (grew from 37 baseline as new modules were added)
Simulated multi-tick soak run | 300 ticks, zero exceptions, valid JSON status output every tick
Simulated full 3-lap integration test (mocked corner sequence) | Correctly reached PARK via 12 corner events → 3 lap increments → THREE_LAPS_COMPLETE + FINISH_ZONE_DETECTED
Simulated parking-zone integration test (real ParkingZoneTracker, synthetic magenta frame) | Correctly reached PARK after PARKING_CONFIRM_FRAMES (5) consecutive sightings
Synthetic-frame lane detection (symmetric walls) | offset_px ≈ 0, confidence 1.0
Synthetic-frame lane detection (asymmetric walls) | Offset sign correctly follows which wall is closer
TOF-aware avoidance steer capping (unit test) | 55° requested → 17° actual when side ToF < TOF_WALL_CRITICAL_MM, direction preserved

### 3.16 Software Design Decisions

Several architectural decisions significantly influenced the final software design.

Deterministic Algorithms

Rather than using machine learning, Hermes uses deterministic computer vision and rule-based decision making.

Advantages include:

- Easier debugging
- Greater reproducibility
- Lower computational requirements
- More predictable behaviour

Distributed Processing

Separating vision from motor control prevents image processing delays from affecting steering performance.

This improves responsiveness and simplifies software development.

Modular Codebase

Each subsystem is implemented as an independent module.

Advantages include:

- Easier maintenance
- Improved readability
- Independent testing
- Simplified future development

26 | P a g e

### 3.17 Summary

The Hermes software architecture combines modular design, deterministic algorithms, and distributed processing to provide reliable autonomous operation. A finite state machine coordinates all robot behaviour, while computer vision provides environmental awareness and a PID controller ensures smooth steering. Communication between the Raspberry Pi and ESP32 separates computationally intensive perception from time-critical motor control, improving both reliability and maintainability. The overall architecture was intentionally designed to prioritize robustness, reproducibility, and explainability in accordance with the WRO 2026 Future Engineers documentation rubric.

### 4. Systems Thinking & Engineering Decisions 4.1 Design Philosophy

Hermes was designed as an integrated engineering system rather than as a collection of independent hardware and software components. Throughout development, every design decision considered how mechanical, electrical, and software subsystems interact to achieve reliable autonomous behaviour.

The team's primary engineering objective was to maximize consistency and repeatability rather than raw speed. The WRO Future Engineers competition rewards robots that complete the challenge reliably and legally, making system robustness more valuable than aggressive performance.

Consequently, the design philosophy adopted throughout the project can be summarized as:

Prioritize reliability, simplicity, and explainability over unnecessary complexity.

This principle influenced every subsystem of the robot.

### 4.2 Overall System Interaction

Hermes follows a layered system architecture where each subsystem performs a specific role before passing information to the next layer.

27 | P a g e


This closed feedback loop repeats continuously throughout autonomous operation.

Each layer receives only the information required to perform its task, reducing coupling between modules and improving maintainability.

### 4.3 Subsystem Responsibilities

To improve modularity, each subsystem has clearly defined responsibilities.

Mechanical System

Responsible for:

- Vehicle stability
- Steering geometry
- Component mounting
- Structural support

The mechanical subsystem provides a stable platform upon which all other systems depend.

Electrical System

Responsible for:

- Power distribution
- Voltage regulation
- Sensor connectivity
- Processor communication

28 | P a g e

Stable electrical performance is essential for reliable software execution and sensor operation.

Perception System

Responsible for transforming raw sensor data into useful environmental information.

Outputs include:

- Track position
- Lane offset
- Pillar colour
- Finish zone detection

The perception system intentionally provides symbolic information rather than directly controlling actuators.

Decision System

The decision layer determines the robot's behaviour using the finite state machine.

Responsibilities include:

- Selecting operating modes
- Planning obstacle avoidance
- Initiating parking
- Determining lap completion

This layer acts as the "brain" of the robot.

Control System

Responsible for converting desired behaviour into physical motion.

Functions include:

- Steering correction
- Speed regulation
- Motion smoothing

The control system ensures that the robot executes decisions predictably.

Firmware

The ESP32 firmware provides deterministic real-time execution.

Responsibilities include:

- PWM generation
- Servo control
- Motor control
- Safety timeout handling

Keeping these tasks separate from the Raspberry Pi improves overall system reliability.

### 4.4 Engineering Constraints

Several constraints influenced the design process.

29 | P a g e

Competition Rules

The robot was required to comply with the WRO Future Engineers regulations, including:

- Four wheels
- One powered axle
- One steering actuator
- Fully autonomous operation
- No wireless communication
- Maximum size restrictions
- Maximum weight restrictions

These constraints limited the range of possible hardware configurations and guided many design decisions.

Computational Resources

Computer vision requires significantly more processing power than real-time motor control.

Rather than forcing a single processor to perform both tasks simultaneously, processing responsibilities were divided between the Raspberry Pi and ESP32.

This reduced processor load and simplified software development.

Reliability

Competition runs provide limited opportunities for recovery from failures.

The robot was therefore designed to minimize:

- Software crashes
- Communication failures
- Mechanical instability
- Electrical resets

Reliability consistently took precedence over performance improvements that introduced additional risk.

### 4.5 Design Trade-offs

Developing Hermes required balancing competing engineering priorities.

Simplicity vs Complexity

Alternative considered:

Machine learning or deep learning for perception.

Reasons not selected:

- Large training datasets required.
- Increased computational requirements.
- Reduced explainability.
- Greater sensitivity to changing lighting conditions.
- Longer development time.

Selected solution:

30 | P a g e

Classical computer vision using deterministic image processing.

Advantages:

- Easier calibration.
- Lower computational cost.
- Predictable behaviour.
- Simpler debugging.

Single Processor vs Distributed Processing

Alternative:

Use only a Raspberry Pi for all tasks.

Potential disadvantages:

- Higher processor utilization.
- Less deterministic motor control.
- Increased software complexity.

Selected solution:

Hybrid Raspberry Pi and ESP32 architecture.

Advantages:

- Improved real-time performance.
- Clear separation of responsibilities.
- Easier debugging.
- Greater fault isolation.

Speed vs Reliability

Higher speeds reduce competition completion time but significantly increase:

- Steering oscillation.
- Cornering errors.
- Sensor noise.
- Risk of leaving the track.

The team therefore prioritized reliable completion of the challenge over minimizing completion time.

This decision influenced:

- Speed controller tuning.
- Obstacle handling.
- Final approach behaviour.
- Parking strategy.

### 4.6 Risk Identification

Several potential risks were identified during development.

Risk | Potential Effect | Mitigation

31 | P a g e
Poor lighting | Incorrect colour detection | Camera calibration and adjustable thresholds
Serial communication failure | Loss of vehicle control | ESP32 watchdog timeout
Sensor noise | Steering instability | Filtering and validation
Voltage drop | Processor resets | Regulated power distribution
Loose wiring | Intermittent failures | Secure cable routing
Incorrect calibration | Poor autonomous performance | Calibration before testing

Risk identification formed an important part of the engineering design proces

### 4.7 Failure Handling

Rather than assuming perfect operating conditions, Hermes was designed to detect and respond safely to failures.

Examples include:

Communication Loss

If communication between the Raspberry Pi and ESP32 stops unexpectedly:

- Motor commands expire.
- The ESP32 stops the drive motor.
- The robot remains stationary.

Invalid Sensor Data

Unexpected or invalid sensor readings are ignored where possible.

Critical failures cause the state machine to enter the ERROR state.

Software Exceptions

The software architecture isolates major functional modules, reducing the likelihood that failures in one subsystem will propagate throughout the robot.

- | Every | hardware-adjacent | constructor | (Camera, | KeyboardOverrideListener.start(),
SerialLink.connect()) wraps its real-backend attempt in try/except Exception, logs a warning, and degrades to a synthetic/emulated fallback rather than propagating.
- packet_parser.parse_incoming() is documented and implemented to never raise - every malformed input path returns a typed dict ({"type": "unknown", ...}) instead.
- SerialLink.send()/read_line()/send_emergency() each wrap the actual pyserial I/O call individually, so a write failure doesn't prevent a subsequent read attempt or vice versa.
- run_forever()'s top-level loop catches KeyboardInterrupt separately from generic Exception (clean shutdown log vs. error-with-traceback log), both funnelling into the same finally: self.shutdown().
- shutdown() itself wraps its emergency-stop send in try/except - a failure to notify the ESP32 during shutdown is logged, not allowed to prevent the rest of cleanup (listener stop, camera close) from running.
- Camera.get_frame()/get_jpeg() wrap the actual hardware capture call, logging and returning None/a synthetic frame on failure rather than raising into the perception pipeline.

32 | P a g e

### 4.8 Iterative Development Process

Hermes was developed using an iterative engineering approach.

Rather than attempting to complete every subsystem simultaneously, development proceeded through repeated cycles of:

Planning → Implementation → Testing → Evaluation → Refinement

Each iteration focused on improving one subsystem while preserving previously verified functionality.

This incremental process reduced integration problems and simplified debugging.

### 4.9 Testing Strategy

Testing occurred at multiple levels.

Unit Testing

Individual modules were tested independently.

Examples include:

- Communication
- State machine
- PID controller
- Vision algorithms

Integration Testing

Subsystems were progressively combined to verify interaction between:

- Perception
- Planning
- Control
- Firmware

System Testing

Complete autonomous runs were performed to evaluate:

- Track following
- Obstacle handling
- State transitions
- Overall reliability

Testing results were used to guide subsequent design improvements.

### 4.10 Engineering Decisions Supported by Testing

Throughout development, design decisions were validated through repeated experimentation rather than assumption.

Examples include:

- Selecting PID parameters based on observed steering behaviour.
- Adjusting sensor placement after testing.
- Refining colour thresholds using camera calibration.

33 | P a g e
- Modifying steering behaviour to reduce oscillation.

Whenever possible, engineering decisions were based on observed system performance rather than theoretical expectations alone. Some design iterations we had:

1. TOF driver + lane detection + obstacle avoidance (first pass) - added the ESP32-side dual-VL53L0X driver, Pi-side camera wall detection, and a ToF-aware cap on the pre-existing pillar-avoidance steering angle.
2. Correctness pass on the above - discovered and fixed a sign/state-tracking issue where testing initially showed TOF capping wasn't triggering; traced to test setup overwriting context before the tick that should've used it, not a code bug - but surfaced the need for more careful integration testing going forward.
3. Lap/corner/finish/parking perception - added CornerTracker and ParkingZoneTracker, discovered along the way that the pre-existing THREE_LAPS_COMPLETE transition was structurally unreachable (event-queue snapshot semantics meant it was always evaluated one state too late) and fixed the transition table.
4. Camera synthetic-frame fix - discovered, while building the lap-counting integration test, that Camera.get_frame() returned None in all simulated runs (only the dashboard JPEG stream had a synthetic fallback), meaning every prior "simulated soak test" claim in this conversation had not actually exercised any vision code path. Refactored the drawing logic into a shared helper so both the JPEG and raw-array paths draw the same scene.

### 4.11 Future Improvements

Several enhancements have been identified for future development.

Potential improvements include:

- Improved sensor fusion using IMU and Time-of-Flight measurements.
- Adaptive speed control based on track geometry.
- More sophisticated obstacle trajectory planning.
- Enhanced parking accuracy.
- Improved diagnostic and logging capabilities.

These improvements can be incorporated without fundamentally changing the overall system architecture.

### 4.12 Summary

Hermes was engineered as a cohesive autonomous system in which mechanical, electrical, and software subsystems work together to achieve reliable performance. Every major design decision considered the interactions between subsystems, the constraints imposed by the competition, and the importance of repeatable behaviour. By favouring deterministic algorithms, modular architecture, distributed processing, and iterative testing, the team developed a robot that is robust, explainable, and maintainable. This systems-oriented approach provides a strong foundation for continued refinement while remaining aligned with the objectives of the WRO 2026 Future Engineers challenge.

### 5. Reproducibility & GitHub Quality 5.1 Project Overview

Hermes was developed with reproducibility as a core objective. The project repository has been structured so that another team can understand the robot's design, reproduce its software architecture, and rebuild the system using the provided documentation, source code, and supporting assets.

34 | P a g e

The repository contains both the high-level Raspberry Pi software and the low-level ESP32 firmware, allowing the complete autonomous system to be recreated from source.

Development was managed using Git and GitHub, enabling version control, collaboration, and traceability of design decisions throughout the project.

### 5.2 Repository Structure

The repository is organized into logical modules that separate responsibilities and improve maintainability.

Top-level structure includes:

Firmware/
ESP32 firmware responsible for:
- Motor control
- Servo control
- Serial communication
- Safety watchdog
- Hardware interfaces

src/
├── communication/
│ └── Configuration and packet handling.
│
├── config/
│ └── Robot configuration and system parameters.
│
├── control/
│ └── Steering control, speed control, and drive command generation. │
├── hardware/
│ └── Hardware interface modules.
│
├── perception/
│ └── Computer vision and environmental sensing. │
├── planning/
│ └── Navigation and obstacle planning.
│
├── simulation/
│ └── Simulation utilities.
│
├── state_machine/
│ └── Finite State Machine implementation. │
├── testing/
│ └── Software testing utilities.
│
├── utils/
│ └── Shared helper functions. │
├── docs/
│ └── Project documentation. │

35 | P a g e

└── assets/
└── Supporting media and design resources.

### 5.3 Software Organization

The software follows a modular architecture in which each module performs one clearly defined responsibility.

This approach provides several advantages:

- Easier debugging.
- Improved readability.
- Simplified maintenance.
- Independent module testing.
- Reduced coupling between components.

For example:

- The perception module processes images but never controls motors.
- The planning module determines desired behaviour but never accesses hardware directly.
- The control module converts desired behaviour into actuator commands without performing computer vision.
- This separation makes the software easier for another team to understand and extend.

### 5.4 Version Control

Git was used throughout development to record software changes and coordinate collaboration between team members.

Version control provides:

- Complete history of software development.
- Ability to recover previous versions.
- Safe experimentation using branches.
- Easier collaboration through pull requests.

The team adopted the following workflow:

- Create feature branches for new work.
- Develop and test features independently.
- Merge completed work into the main branch using pull requests.
- Synchronize repositories using Git Fetch and Git Pull before beginning new work.

This workflow minimizes merge conflicts and improves software quality.

### 5.5 Commit History

Meaningful commit messages were used to document project progress. And changes were made via branch and Pull Requests, never directly to the main branch.

Rather than committing unrelated changes together, commits represent individual engineering tasks or feature additions.

Examples include:

- feat: perception
- feat: lane following


36 | P a g e
- chore: clean up comments
- fix: duplicate method in state machine

A well-maintained commit history allows the development process to be reconstructed and demonstrates continuous progress throughout the project.

### 5.6 Documentation

The project documentation has been prepared to allow another team to understand both the implementation and the engineering reasoning behind the robot.

Documentation includes:

- Mechanical design.
- Power architecture.
- Sensor placement.
- Software architecture.
- System interactions.
- Engineering decisions.
- Testing methodology.
- GitHub repository information.

Where appropriate, diagrams are included to improve clarity and reproducibility.

Documentation emphasizes not only what was built, but also why each design decision was made.

### 5.7 Supporting Files

The repository includes all resources necessary to understand the robot's design.

Supporting materials include:

- Source code.
- Firmware.
- Configuration files.
- Documentation.
- CAD files.
- Wiring diagrams.
- Testing utilities.

These resources collectively provide sufficient information for another team to reproduce the system.

Even CAD models are present in the /models directory.

Wiring Diagrams (System and ESP)

37 | P a g e

### 5.8 Build and Setup Process

A new user can reproduce the software by following the documented setup process.

Typical setup includes:

1. Clone the repository.
2. Install required software dependencies.
3. Configure the Raspberry Pi.
4. Upload firmware to the ESP32.
5. Connect hardware according to the wiring diagram.
6. Calibrate sensors.
7. Verify serial communication.
8. Execute autonomous software.

Providing a structured setup process reduces ambiguity and improves reproducibility.

### 5.9 Hardware Reproducibility

The hardware design has been documented to enable reconstruction by another team.

This includes:

- Bill of Materials.
- Component descriptions.
- Sensor placement.
- Power architecture.
- Mechanical layout.

Where custom parts are used, CAD models are included in the repository.

38 | P a g e

### 5.10 Testing Workflow


### 5.11 Reproducing the Robot

A team attempting to recreate Hermes should follow the following sequence:

1. Assemble the chassis.
2. Install all electronic components.
3. Complete power wiring.
4. Upload ESP32 firmware.
5. Configure the Raspberry Pi software.
6. Install software dependencies.
7. Connect the Raspberry Pi and ESP32 through serial communication.
8. Calibrate camera and sensors.
9. Verify steering and motor operation.
10. Test lane following.
11. Test obstacle avoidance.
12. Perform complete autonomous runs.

Following this sequence minimizes integration problems and allows faults to be isolated more effectively.

### 5.12 Future Repository Improvements

Several improvements have been identified that would further enhance reproducibility.

These include:

- Automated installation scripts.
- Dependency management documentation.

39 | P a g e
- Release version tagging.
- Continuous integration testing.
- Expanded troubleshooting documentation.
- Hardware calibration checklists.
- Additional configuration examples.

These improvements would simplify onboarding for future team members and external users.

### 5.13 Summary

Hermes was developed with reproducibility as a fundamental design objective. A modular repository structure, meaningful version control practices, comprehensive documentation, and clearly separated software components allow another team to understand, rebuild, and extend the robot with minimal ambiguity. By documenting both the implementation and the engineering decisions behind it, the project satisfies the goals of transparency, maintainability, and reproducibility expected by the WRO 2026 Future Engineers documentation rubric.

40 | P a g e

Appendix A - Testing and Design Iterations
A.1 Development Methodology
The development of Hermes followed an iterative engineering process in which each subsystem was designed, tested, evaluated, and refined before being integrated into the complete robot. This approach allowed faults to be isolated more effectively and ensured that improvements in one subsystem did not unintentionally reduce the performance of another.

Rather than attempting to complete the entire robot in a single development cycle, the team adopted a continuous improvement workflow consisting of:

Planning → Implementation → Testing → Evaluation → Refinement

Each iteration focused on improving a specific subsystem while maintaining the overall stability of the robot.

A.2 Mechanical Iterations
Several revisions were made to the mechanical design throughout development.

Final Inplementation

Objective:
Produce the competition-ready configuration.

Final improvements included:

- Improved structural rigidity.
- Improved component accessibility.
- Cleaner cable routing.
- Stable sensor mounting.

A.3 Software Development Timeline
Software development progressed in stages rather than being developed simultaneously.
1. Architecture phase (early) - Pi/ESP32 ownership split established, I2C sensor addresses documented, ESP32 pin map drafted, Python module structure (serial comms, packet parsing, state machine, drive commands, logging) laid out.
2. Core comms + state machine build - serial protocol, packet parser, event queue, state transitions, RobotContext; git branch corruption (main vs feat/DriveCommand) resolved along the way.
3. State machine audit - checked against competition spec for correctness.
4. Firmware serial layer refactor - Pi-side serial layer rewritten, matching typed ESP32 firmware endpoints; a telemetry function naming conflict resolved.
5. Motor control implemented, servo control verified, PWM output tested.
6. Camera integrated, Vision pipeline implemented.
7. Firmware driver, camera-based lane detection, TOF-aware obstacle-avoidance capping.
8. Lap/corner counting, finish-zone and parking-zone detection, state-machine transition bugfix.

### 9. Camera simulated-frame fallback fix, enabling vision code to actually run under

simulated=True.
10. Full autonomous state machine completed.

A.4 Communication Testing
Reliable communication between the Raspberry Pi and ESP32 was critical to the robot's operation.

41 | P a g e

Testing focused on:

- Packet transmission.
- Packet parsing.
- Response timing.
- Invalid packet handling.
- Communication recovery.

During development, several communication issues were encountered and resolved.

Examples included:

- Incorrect UART configuration.
- Packet synchronization issues.
- Timeout handling.
- Serial buffer management.

Solutions implemented included:

- Standardized packet formatting.
- Packet validation before execution.
- Communication timeout detection.
- Automatic motor shutdown if communication is lost.

A.5 PID Steering Tuning
The steering controller was tuned experimentally.

Each adjustment involved:

1. Selecting new PID gains.
2. Driving multiple laps.
3. Observing oscillation.
4. Recording behaviour.
5. Refining controller parameters.

Performance was evaluated according to:

- Steering smoothness.
- Overshoot.
- Cornering accuracy.
- Lane-centreing performance.

Final PID gains

Parameter | Value
STEER_PID_KP | 1.6
STEER_PID_KI | 0.02
STEER_PID_KD | 0.35
Output clamp | ±45° (correction authority, not full steering range)
Integral anti-windup clamp | ±20°·s
Servo slew limit | 12°/tick at the 20Hz control loop

42 | P a g e

A.6 Vision Testing
Computer vision was evaluated under multiple lighting conditions.

Testing considered:

- Bright lighting.
- Indoor lighting.
- Shadows.
- Variable reflections.

Calibration focused on:

- Colour thresholds.
- Exposure.
- White balance.
- Region-of-interest placement.

These adjustments improved the consistency of obstacle detection and lane estimation.

A.7 System Testing
Full-system testing evaluated the interaction between all subsystems.

Testing scenarios included:

- Straight-line driving.
- Cornering.
- Obstacle avoidance.
- Lap counting.
- Finish detection.

Each test was repeated multiple times to evaluate repeatability.

Performance metrics were recorded.

A.8 Lessons Learned
Several important engineering lessons were identified during development.

Examples include:

- Modular software significantly simplified debugging.
- Separating perception and control reduced software complexity.
- Reliable communication is more important than communication speed.
- Mechanical alignment greatly influences software performance.
- Small hardware adjustments can significantly improve autonomous behaviour.

Appendix B - Mechanical Drawings, Wiring and CAD References
B.1 Mechanical Drawings
The repository contains the CAD models used during development.

These models describe:

- Chassis geometry.
- Mounting brackets.
- Sensor mounts.


43 | P a g e
- Structural components.

For brevity, the complete CAD models are provided in the project repository rather than embedded within this document.

B.2 Wiring Diagram

B.3 Sensor Placement
The sensor arrangement was selected to maximize environmental awareness while minimizing interference.

Camera: Front-mounted with forward-facing field of view.

IMU: Mounted near the centre of mass.

Time-of-Flight Sensors: Mounted on the sides of the vehicle for lateral distance measurement.

B.4 Mechanical Assembly
The robot was assembled using a modular approach.

Major assembly stages included:

1. Chassis assembly.
2. Steering installation.
3. Drive motor installation.
4. Battery installation.
5. Sensor mounting.
6. Electronics installation.
7. Wiring.
8. Software upload.
9. Calibration.

Appendix C - Bill of Materials
Materials | Description | quantity | cost | URL
VL53L1X (TOF) | Measuring distance | 4 | GHC 67.03 | 1/3/5pcs VL53L0X Time-of-Flight (ToF) Laser Ranging Sensor Breakout
Raspberry pi 4 | Process data from Pi-Cam | 1 | Covered | Covered
Pi-Cam 3 | For computer vision | 1 | GHC 98.10 | Raspberry Pi Camera Module
ESP-WROOM-32 | Sensor integration and motor control | 1 | GHC 64.00 | N/A

44 | P a g e
DC Motor | Bot Movement | 1 | GHC 85.00 | DC12V N20 600rpm Micro Metal Gear Motor
DRV8833 Driver | Controlling motor direction and speed | 1 | GHC 85.93 | Set of 4 DRV8833 Motor Driver Modules,
18650 2000mAh 3.7V Rechargeable Lithium Battery | Power Supply | 2 | GHC 50 | 3.7V 18650 Lithium ion Battery Single 2550mah
Battery holder | Contain the batteries | 1 | GHC 28.00 | 2 x 18650 Battery Holder with Cover & ON/OFF Switch
Power switch | Turn on/off the bot. | 1 | GHC 2.00 | 2Pin SPST Mini Boat Rocker Switch 3A 250V Red
Charging Module | Charge the batteries | 1 | GHC 36.27 | Dual-slot 18650 Lithium Battery Charger, 4.2V Smart Fast Charging, Black Universal Charging Dock
Buck converter 7.4 V → 5 V (3 A+) | Regulate Voltage | 1 | GHC 18.00 | LM2596 LM2596S DC-DC Step- Down Buck Converter Module with SMD LED
MPU6050 | Gyroscope/Motion Sensing | 1 | GHC 42.00 | MPU-6050 3 Axis Acceleration + Gyro Breakout
MG90S Servo | Position-controlled movement | 1 | GHC 38.00 | MG90S – Metal Gear Micro Servo Motor
LSM6DSOX IMU | Movement and orientation tracking | 1 | Covered | Covered

C.1 Estimated Cost
We invested approximately GH₵ 600.00 and a lot of time into this project.

C.2 Component Selection Rationale
Each major component was selected according to engineering requirements rather than availability alone.
- Raspberry Pi 4: Provides sufficient processing power for computer vision and high-level planning.
- ESP-WROOM-32: Offers reliable real-time control, PWM generation, and serial communication.
- Camera Module: Enables lane and obstacle detection using computer vision.
- MG90S Servo: Provides paccurate and repeatable steering control.
- Time-of-Flight Sensors: Supply direct distance measurements that complement vision.
- IMU: Provides orientation and motion data for improved state estimation.
- Lithium-ion Battery Pack: Offers a high energy density suitable for repeated autonomous runs.

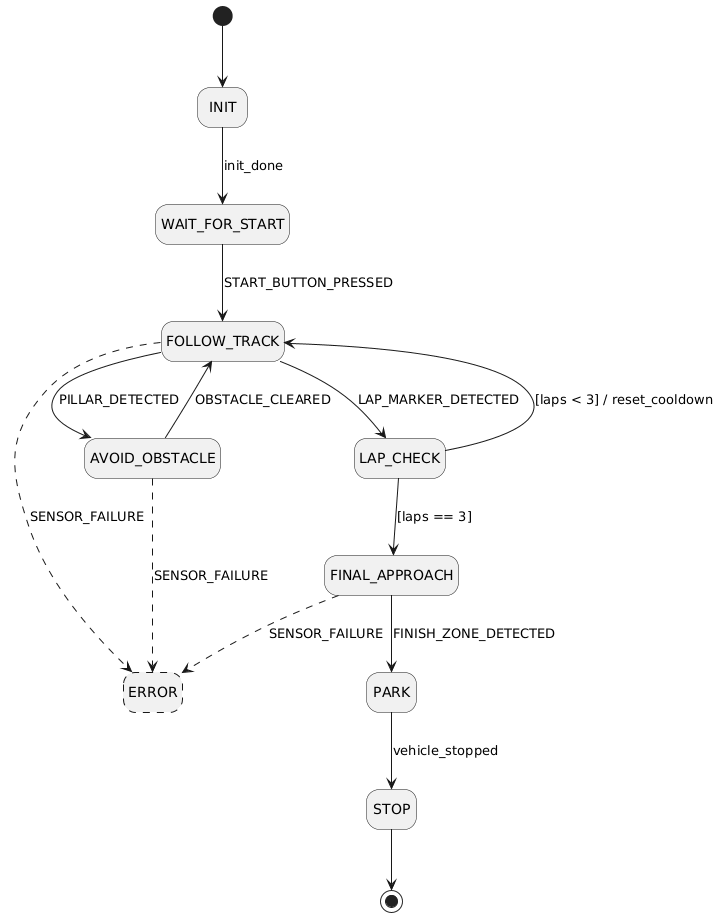
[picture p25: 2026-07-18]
other/State_Transition_Diagram.png

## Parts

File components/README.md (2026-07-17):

# WRO Future Engineers - Robot Component Reference

This folder is a component-only reference for the robot hardware used in the WRO 2025 Future Engineers project.
It intentionally avoids schematics, wiring, power-chain notes, firmware details, and software architecture.
This documentation was last updated on **Thursday, July 16, 2026**.

---

## Component Gallery

<div align="center">
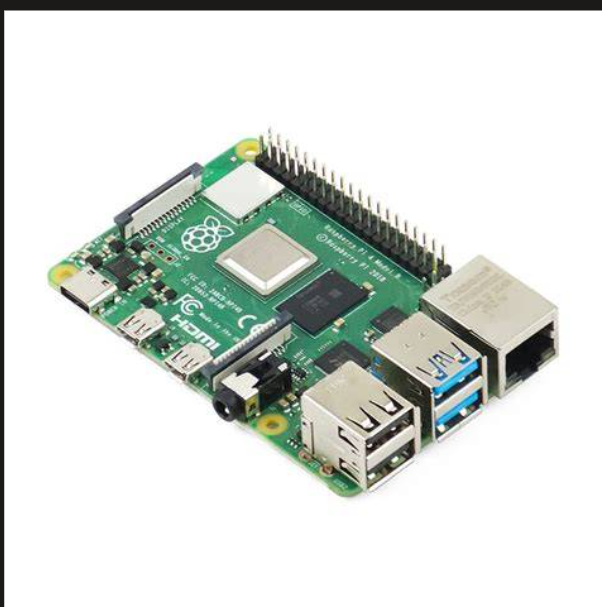
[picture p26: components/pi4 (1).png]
Raspberry Pi 4

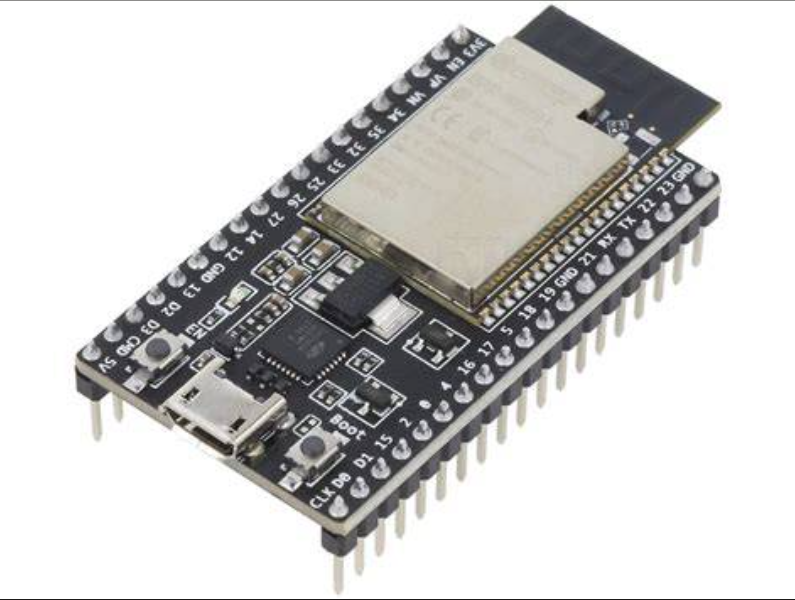
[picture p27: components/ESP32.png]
ESP32 DevKit

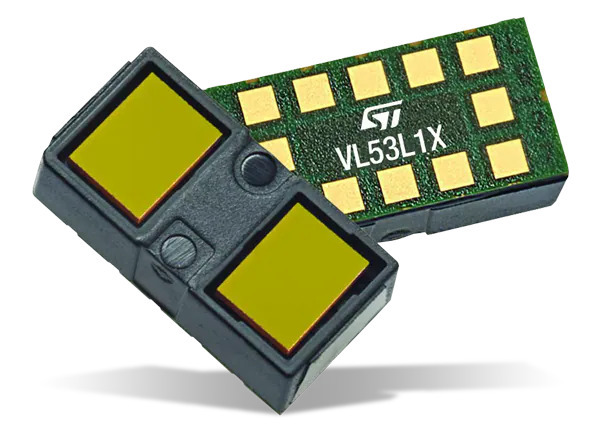
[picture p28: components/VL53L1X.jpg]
VL53L1X ToF Sensor

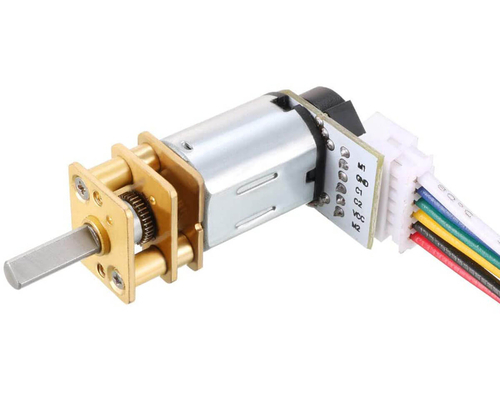
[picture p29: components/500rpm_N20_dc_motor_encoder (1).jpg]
N20 Motor with Encoder

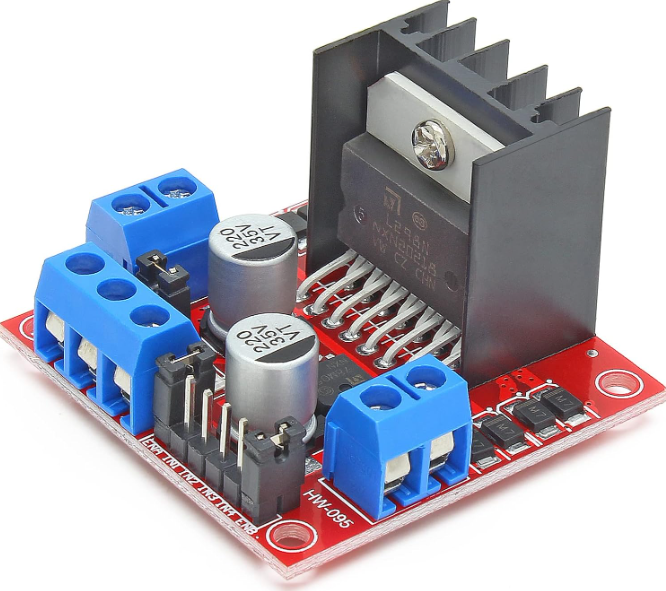
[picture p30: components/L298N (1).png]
L298N Motor Driver

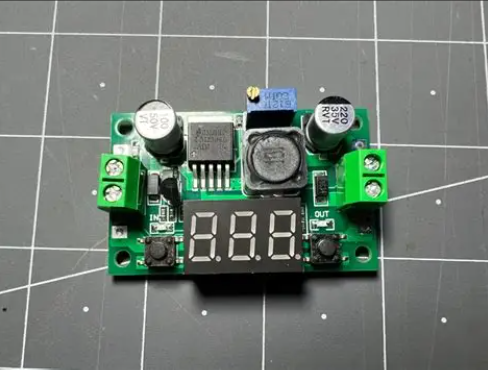
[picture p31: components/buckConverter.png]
Buck Converter

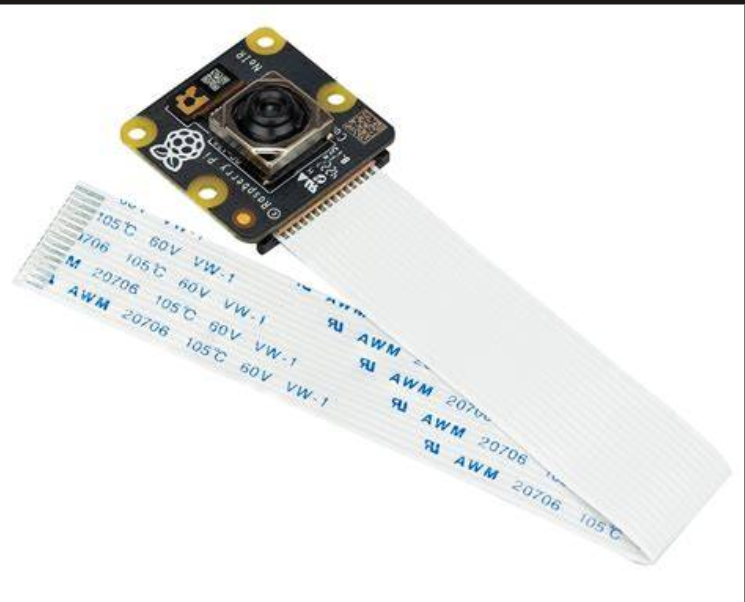
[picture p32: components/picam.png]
Raspberry Pi Camera

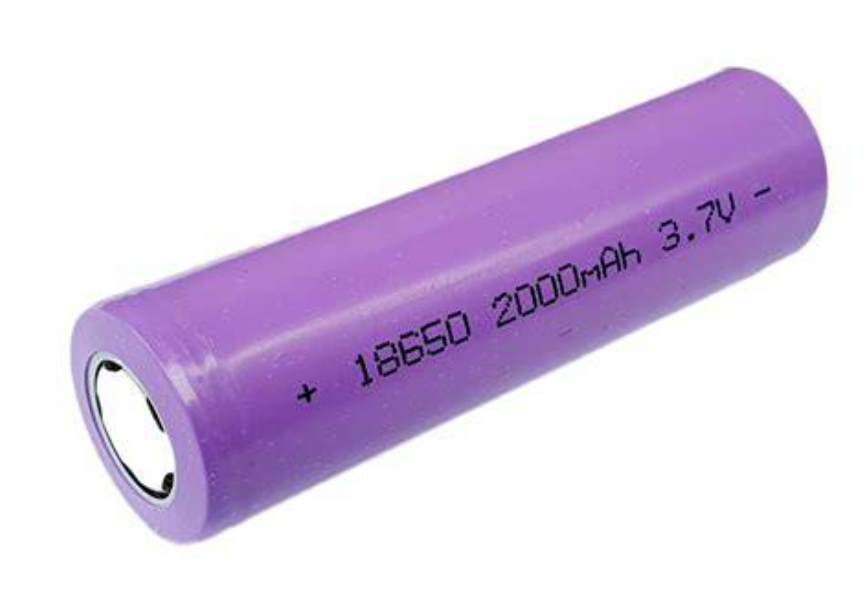
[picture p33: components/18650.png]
18650 Battery

</div>

---

## Components Used

| Component | Role |
|---|---|
| Raspberry Pi 4 | High-level computing platform |
| ESP32 DevKit | Embedded control and sensor processing |
| LSM6DSO IMU | Motion and orientation sensing |
| VL53L1X ToF Sensor | Distance sensing |
| N20 Gearmotor with Encoder | Drive motor and feedback |
| L298N Motor Driver | Motor driver module |
| Steering Servo | Front steering actuation |
| 18650 Li-ion Battery Pack | Main power source |
| Buck Converter | Voltage regulation |
| Raspberry Pi Camera v3 | Vision input |

---

## Datasheets

PDF datasheets for each component will be uploaded here.

file names:

- `raspberry_pi_4_datasheet.pdf`
- `esp32_datasheet.pdf`
- `lsm6dso_datasheet.pdf`
- `vl53l1x_datasheet.pdf`
- `n20_motor_encoder_datasheet.pdf`
- `l298n_datasheet.pdf`
- `servo_datasheet.pdf`
- `18650_battery_datasheet.pdf`
- `buck_converter_datasheet.pdf`
- `pi_camera_v3_datasheet.pdf`

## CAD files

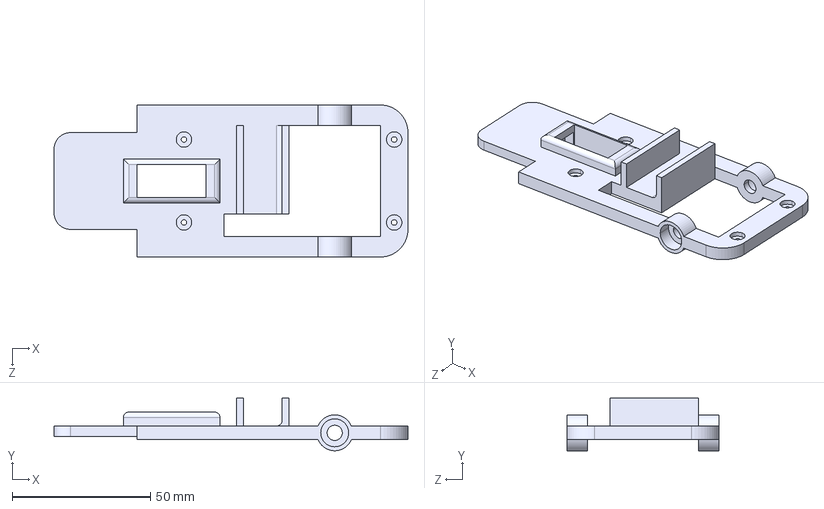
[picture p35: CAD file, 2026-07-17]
models/main_base.STEP
128.0 x 19.0 x 55.0 mm

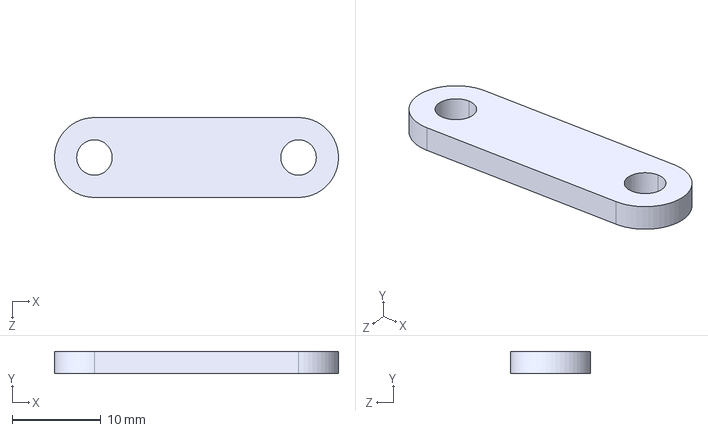
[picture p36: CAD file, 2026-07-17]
models/linkage.STEP
32.0 x 2.50 x 9.00 mm

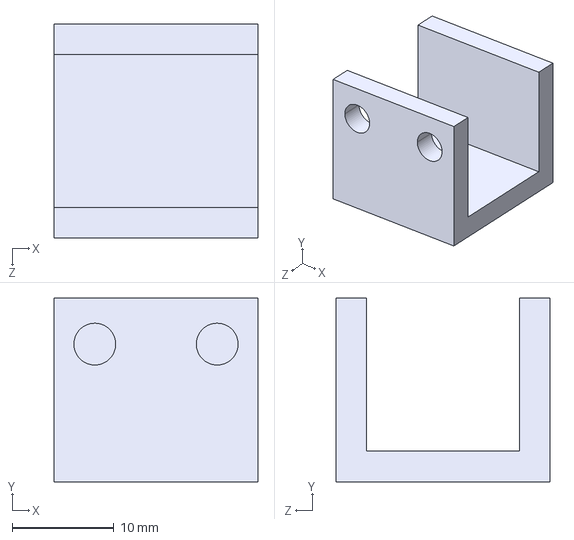
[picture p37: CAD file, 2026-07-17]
models/forward_clip.STEP
20.0 x 18.0 x 21.0 mm

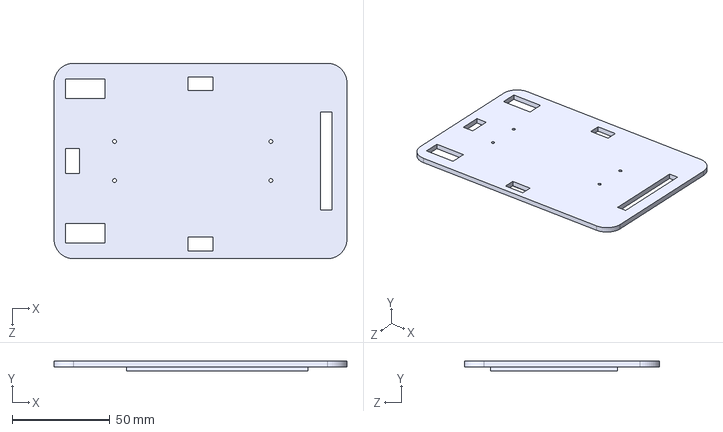
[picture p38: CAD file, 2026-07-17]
models/top_layer.STEP
150.0 x 5.00 x 100.0 mm

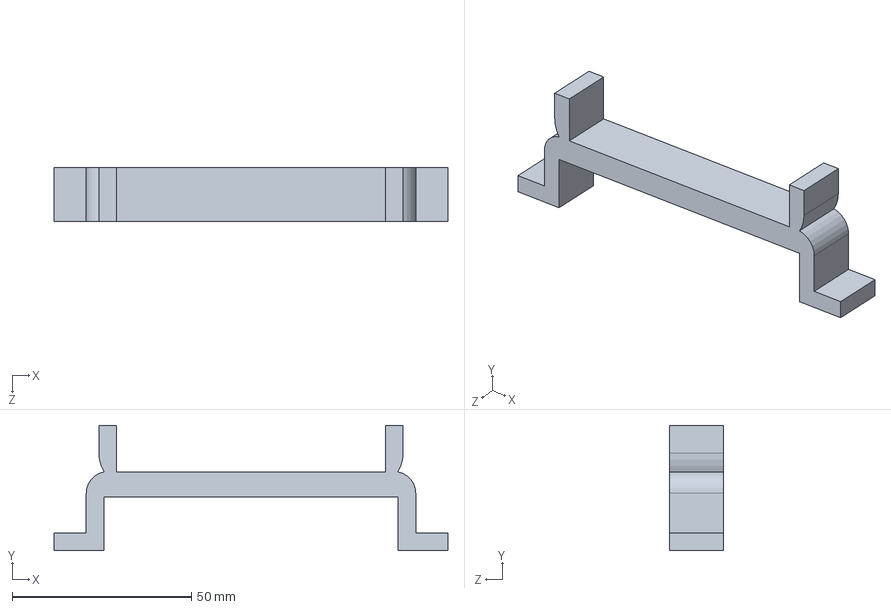
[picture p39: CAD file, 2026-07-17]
models/sensor_box_holder.SLDPRT
110.0 x 35.0 x 15.0 mm

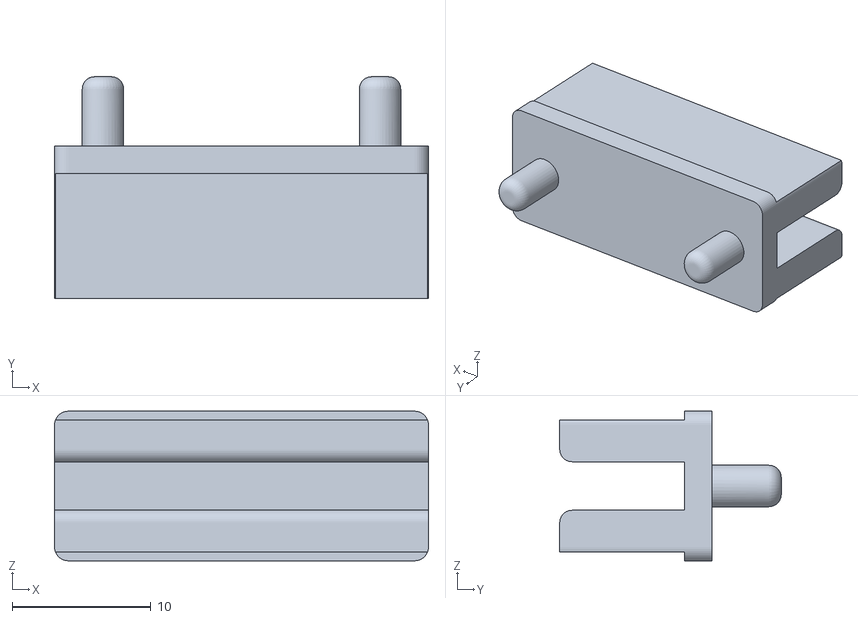
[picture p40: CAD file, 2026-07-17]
models/tof_mount.STL
27.0 x 16.0 x 10.8

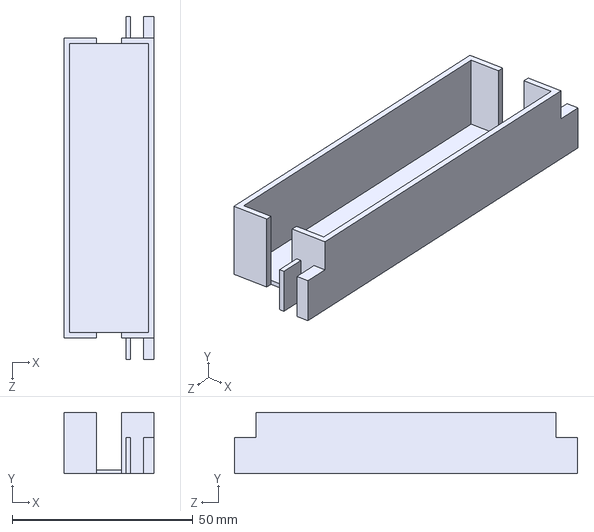
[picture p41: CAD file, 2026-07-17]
models/battery_holder.STEP
25.0 x 17.0 x 95.0 mm

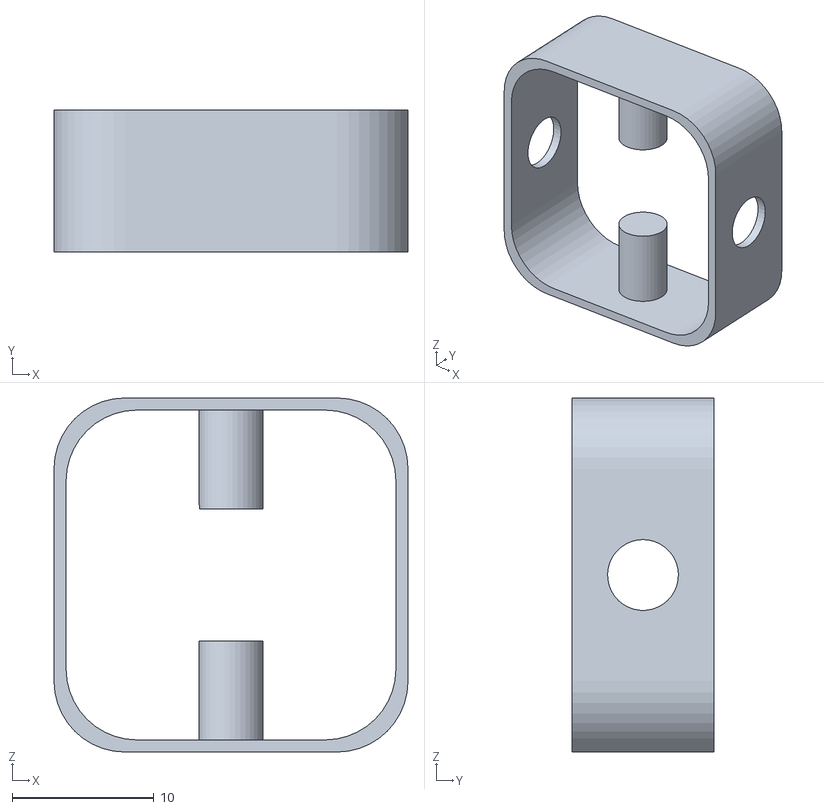
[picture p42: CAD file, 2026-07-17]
models/nDifferential_gearbox.STL
25.0 x 10.0 x 25.0

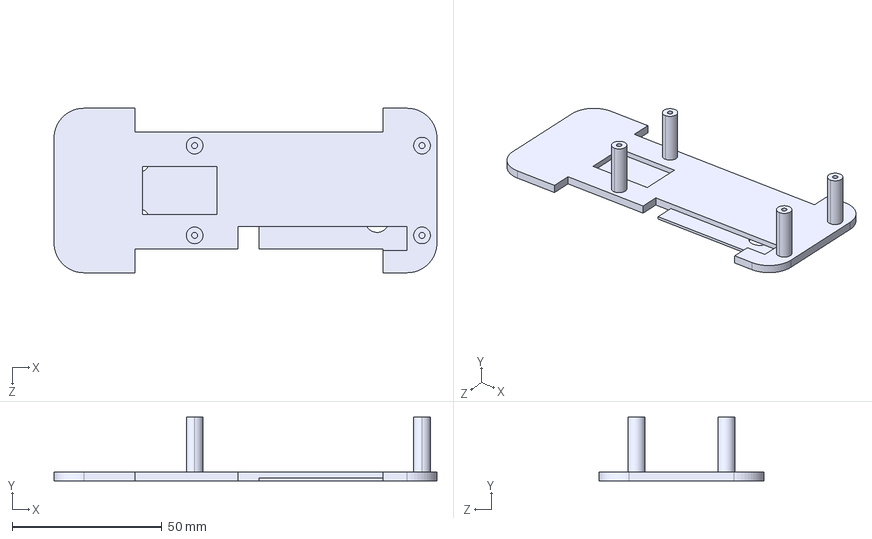
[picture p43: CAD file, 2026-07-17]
models/power_layer.STEP
128.0 x 21.3 x 55.0 mm

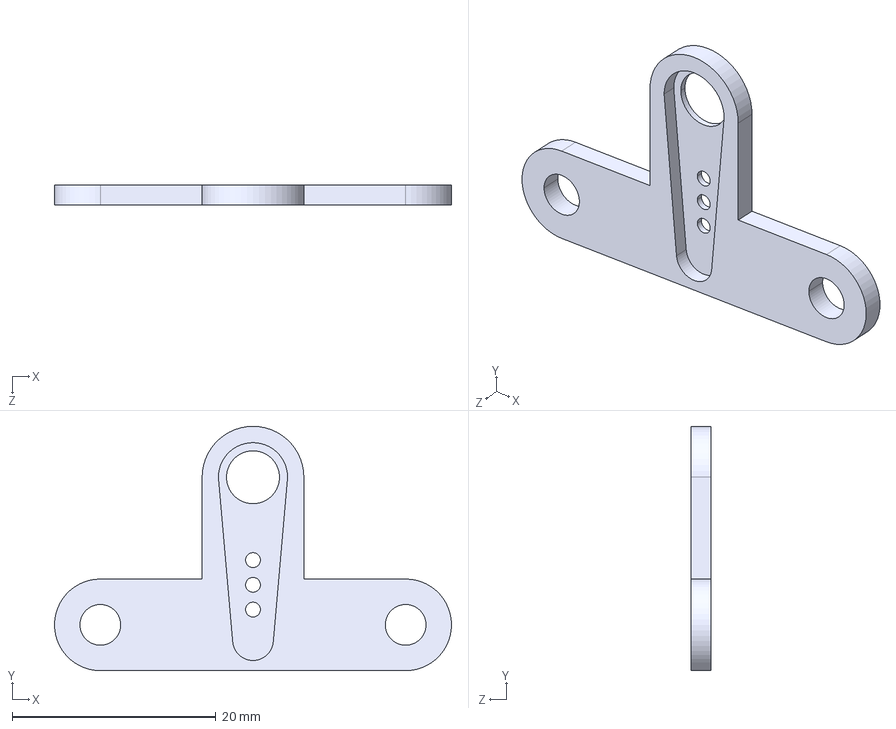
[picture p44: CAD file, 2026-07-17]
models/servo_linkage.STEP
39.0 x 24.0 x 2.00 mm

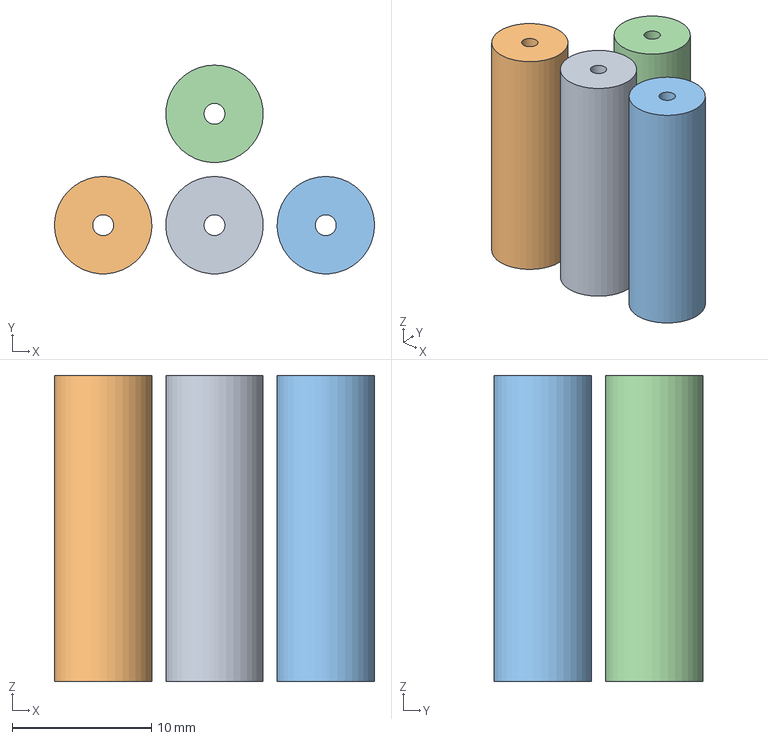
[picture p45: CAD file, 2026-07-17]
models/hold.3mf
23.0 x 15.0 x 22.0 mm
hold.STL x 4

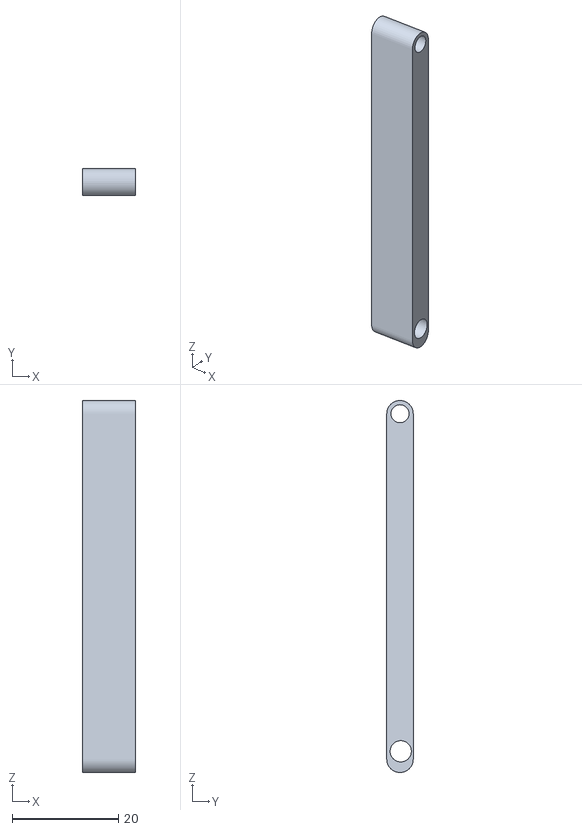
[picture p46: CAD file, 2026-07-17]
models/cam_plate.STL
10.00 x 5.00 x 70.0

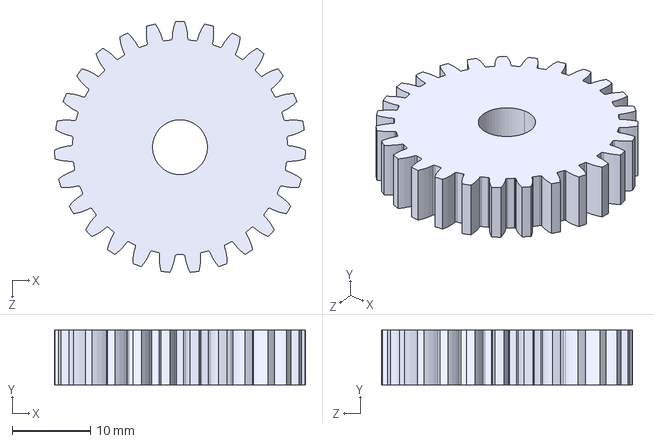
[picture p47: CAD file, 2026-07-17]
models/second_spur_gear.STEP
32.0 x 7.00 x 31.9 mm

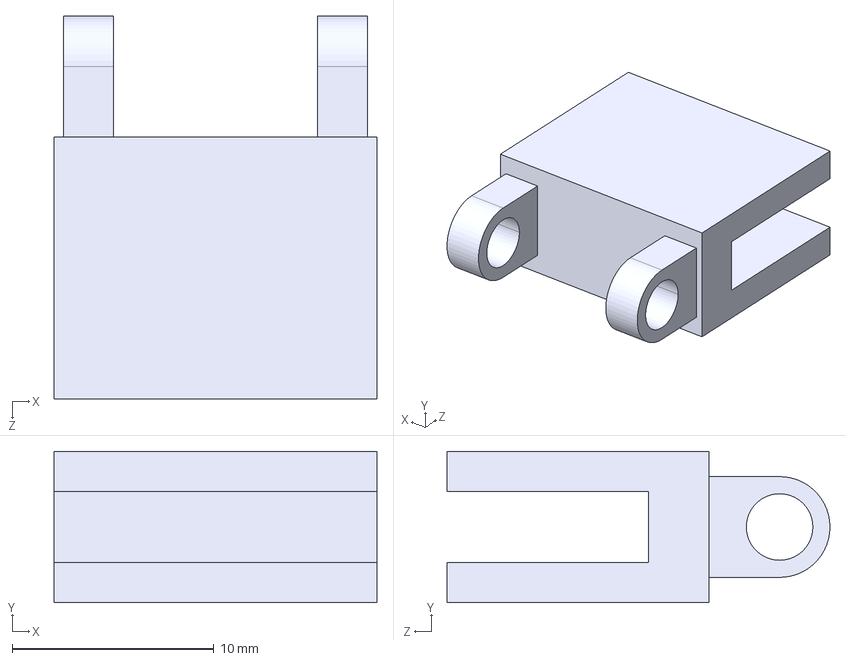
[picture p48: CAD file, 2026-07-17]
models/cam_clip.STEP
16.0 x 7.50 x 19.0 mm

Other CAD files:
models/Assem1.SLDASM
models/rod_actual.SLDPRT
models/pin.STL
models/bevel gear.STEP
models/first_spur.STEP
models/sensor_box.SLDPRT
models/sensorfusion_layer.STEP

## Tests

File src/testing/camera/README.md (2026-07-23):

# Camera / Vision test suite

Everything the camera is responsible for, split into **one test per job** so a
failure points at exactly one subsystem. Work top-to-bottom: don't trust the
pillar test until Job 1 (the pixels themselves) is green, because every
detector downstream is only as correct as the frame it's handed.

| # | Job | Source file | Test file | Output it produces |
|---|-----|---|---|---|
| 1 | Frame acquisition | `perception/camera.py` | `frame_source_test.py` | RGB array + JPEG stream |
| 2 | Pillar detect + avoid | `perception/pillar_detection.py` | `pillar_test.py` | colour, pass-side, steer, distance |
| 3 | Corner markers → laps | `perception/corner_detection.py` | `corner_test.py` | orange/blue edges |
| 4 | Parking zone | `perception/finish_detection.py` | `parking_test.py` | magenta confirmed |
| 6 | Integration / gating | `runtime.py` | `integration_test.py` | laps, mode, state gating |

> **Lane / wall centering is no longer a camera job.** The forward camera's
> FOV is too narrow to see both walls, so corridor centering moved to the side
> ToFs + IMU (`planning/wall_centering.py`, tested by
> `testing/test_wall_centering.py`). The camera now only does pillars, corner
> markers, and the parking zone. That's why there is no Job 5 here.

Plus two calibration tools: `calibrate_hsv.py` (colour bounds) and
`calibrate_focal.py` (pillar-distance focal length).

---

## Each test has two modes

* **`--selfcheck`** — synthetic frames, **no camera needed**. Verifies the
  *logic* (thresholds, sign conventions, hysteresis, lap math). Run these
  anywhere, including CI. They must ALL pass before you touch hardware.
* **live** (no flag) — grabs real pixels through the project `Camera` object
  and prints telemetry every tick. This is the **in-person** test: you move a
  pillar / marker / wall in front of the lens and watch the numbers. Ctrl-C to
  stop. Annotated debug frames are dropped in `testing/camera/_debug_out/`
  (git-ignored) for you to `scp` back and eyeball.

Job 6 has no live mode — it's pure logic; its hardware half is the
"On-robot end-to-end" section near the bottom.

## Setup

Run everything from the **`src/` directory**:

```bash
cd src
```

On the Pi you need the real-camera stack (the rest is stdlib):

```bash
sudo apt install -y python3-picamera2      # Pi Camera on Bookworm
pip install numpy pillow opencv-python     # perception maths + encode/masks
```

`--selfcheck` and every live test need `numpy` + `opencv-python`. `picamera2`
is only needed for the actual Pi Camera; without it the suite falls back to a
USB webcam (OpenCV) and then to synthetic frames.

## Fast path: prove the logic first (no hardware)

```bash
cd src
for j in frame_source pillar corner parking; do
  echo "== $j =="; python -m testing.camera.${j}_test --selfcheck || echo "  ^ FAILED"
done
python -m testing.camera.integration_test
python -m unittest testing.test_wall_centering   # ToF+IMU centering (not a camera job)
```

Every block ends in `SELF-CHECK: PASS` / `INTEGRATION: PASS`. If any line reads
`FAIL:` you have a code/config regression — fix that before the mat session,
because live testing can't distinguish "bad code" from "bad lighting".

---

## Job 1 — Frame acquisition

```bash
python -m testing.camera.frame_source_test          # live; point at a PURE RED object
python -m testing.camera.frame_source_test --selfcheck
```

**Do in person:** fill the centre of the frame with a known **pure red** object.

**Expected live output:**
```
source: picamera2                 <- NOT synthetic, NOT opencv, on the Pi
shape:  (240, 320, 3)   (expected (240, 320, 3))
fps:    ~12-15
centre patch  R=~200  G=low  B=low     <- R dominant == channel order OK
JPEG: 4000-9000 bytes, magic OK
saved .../job1_frame.png
```
Open `job1_frame.png`: **red must look red, not blue; no pink cast anywhere.**

**Known bugs & fixes**

| Symptom | Cause | Fix |
|---|---|---|
| `source: synthetic` on the Pi | picamera2 & OpenCV both failed to open | `libcamera-hello` to test the sensor; reseat the ribbon; `sudo apt install python3-picamera2`; check `Camera._open_real` logs at DEBUG |
| Red object shows **B** dominant / image is pink/magenta | R/B channels swapped | The swap lives in `Camera._swap_rb` / `get_frame` / `_real_jpeg` (`camera.py`). Picamera2 `RGB888` actually returns BGR, so `get_frame` must flip once. Don't flip twice — flipping in both `get_frame` and `_real_jpeg` cancels for the stream but leaves perception wrong (or vice-versa). Test the array (this test) AND the dashboard image together. |
| `shape` is `(240,320,4)` | camera returns RGBA/XRGB | `_swap_rb` already handles 4-channel; make sure perception still gets 3 — check `create_preview_configuration` format |
| `fps` far below 15 | resolution/format too heavy, or CPU pegged | lower `FRAME_WIDTH/HEIGHT` in `camera_config.py`, or the fps arg to `Camera()` |
| `get_frame() returned None` | real backend read failed this tick | transient is fine; constant means the device died — re-open |

---

## Job 2 — Pillar detection & avoidance

```bash
python -m testing.camera.pillar_test          # live; real red/green pillar
python -m testing.camera.pillar_test --selfcheck
```

**Do in person:**
1. Hold a **red** pillar centre-frame → expect `RED … pass RIGHT steer=+NN`.
2. Hold a **green** pillar → expect `GREEN … pass LEFT steer=-NN`.
3. **Slide** it left→right across the frame: sign stays correct, `|steer|`
   never drops below **18°**, never exceeds **60°**.
4. **Walk** it toward the camera: `~mm` shrinks. (Its absolute value is only
   right after `calibrate_focal.py` — Job 2 checks the *trend*, not the value.)
5. Cover the pillar: after **5** empty frames you get `CLEARED`.

**Expected live output:**
```
RED    cx=178 area=  920 -> pass RIGHT steer=+27 ~430mm  new=1 clr=0
RED    cx=181 area= 1100 -> pass RIGHT steer=+26 ~390mm  new=0 clr=0
--     (no pillar)
CLEARED (RED)
```

**Known bugs & fixes**

| Symptom | Cause | Fix |
|---|---|---|
| Red/green pillar never detected | HSV bounds off for your lighting | `python -m testing.camera.calibrate_hsv --color RED` (and `GREEN`), paste bounds into `camera_config.py` |
| Red detected only sometimes | red wraps the 0/180 hue boundary; only one of the two ranges is tuned | keep BOTH `HSV_RED_LOW1/HIGH1` and `HSV_RED_LOW2/HIGH2`; widen the one your lighting hits |
| Detects tiny specks as pillars | `MIN_PILLAR_AREA` too low for the noise | raise it in `camera_config.py`; confirm with the `--selfcheck` area test |
| Steer sign backwards (turns INTO the pillar) | `decide_direction` / `compute_steer_angle` sign, OR the servo wiring is mirrored | this test proves the *software* sign; if software is right but the car still turns wrong, it's `STEER_CENTER_DEGREE`/servo polarity in firmware, not here |
| `~mm` wildly wrong | `CAMERA_FOCAL_PX` uncalibrated | run `calibrate_focal.py` |
| Avoidance ends too early / never ends | clear logic: shrinking + within `PILLAR_CLEAR_DISTANCE_MM`, or 5 lost frames | tune `PILLAR_CLEAR_DISTANCE_MM` / `PILLAR_LOST_FRAMES`; the two clear paths are both in the `--selfcheck` |

---

## Job 3 — Corner markers → laps

```bash
python -m testing.camera.corner_test          # live; orange/blue floor line
python -m testing.camera.corner_test --selfcheck
```

**Do in person:** slide an orange (or blue) floor strip through the **bottom**
of the frame. Expect **exactly one** `new=1` as it enters and **one** `CLEARED`
a few frames after it leaves — not a burst.

> The camera only reports the *edges*. Turning edges into a lap count is Job 6.
> Each corner has **two** lines (entry + exit), so one corner = 2 lines, one
> lap = 4 corners = **8 lines**, and a 3-lap run = **24 lines**. This test only
> checks that a single line is detected/classified cleanly; the pairing of two
> lines into one counted corner is Job 6.

**Expected live output:**
```
ORANGE new=1 clr=0
ORANGE new=0 clr=0
--
CLEARED (ORANGE)
```

**Known bugs & fixes**

| Symptom | Cause | Fix |
|---|---|---|
| Orange reads as red, or blue as something else | orange/blue bounds overlap pillar/parking hues | bounds are deliberately spaced (`camera_config.py:24-31`); re-tune with `calibrate_hsv --color ORANGE`/`BLUE`; keep them in the documented gaps |
| Marker flickers new/clear rapidly | thin 20 mm line dips below `MIN_CORNER_MARKER_AREA` | that's why `MIN_CORNER_MARKER_AREA` (150) is lower than a pillar; lower it more or raise the ROI light; `CORNER_MARKER_LOST_FRAMES` hysteresis absorbs single drops |
| Corner miscounts a lap | counting is Job 6, not here | if edges here are clean but laps are wrong, the bug is in `runtime.py` — run `integration_test.py` |

---

## Job 4 — Parking zone (magenta)

```bash
python -m testing.camera.parking_test          # live; magenta parking line
python -m testing.camera.parking_test --selfcheck
```

**Do in person:** show the magenta line steadily → after **5** consecutive
frames you get `CONFIRMED` **once**, then it latches (silent forever after).
Flash it for <5 frames → **no** confirm.

**Expected live output:**
```
seen cx=160 area= 640  consec->
seen cx=161 area= 655  consec->
CONFIRMED cx=160 area=655  (latched)
--
```

**Known bugs & fixes**

| Symptom | Cause | Fix |
|---|---|---|
| Magenta never confirms | bounds off, or marker too small | `calibrate_hsv --color MAGENTA`; check `MIN_PARKING_MARKER_AREA` |
| Confirms off a brief glint | `PARKING_CONFIRM_FRAMES` too low | raise it in `camera_config.py` |
| Re-fires repeatedly | latch broke (`_raised` reset) | should latch until `reset()` at run start — see `ParkingZoneTracker`; the `--selfcheck` guards this |
| Red pillar sometimes reads as magenta | red-high range and magenta range are adjacent on the hue circle | keep `HSV_RED_HIGH2` ending below `HSV_MAGENTA_LOW`; re-tune both |

---

## (Former Job 5) Lane / wall centering — moved to ToF + IMU

Corridor centering is no longer camera-based. It now lives in
`planning/wall_centering.py` and is driven from the two side ToF distances on
the context every tick (`runtime._update_wall_centering`). Test it with:

```bash
cd src
python -m unittest testing.test_wall_centering        # logic (signs, modes, bias, clamp)
```

**Do in person (on the robot):** in a real corridor, watch the dashboard/logs
`centering` field (`mode`, `offset_mm`). Physically slide the robot toward the
**right** wall → `offset_mm` goes **positive** and the heading target nudges
**left** (negative), steering back to centre. Remove one wall → `mode` becomes
`LEFT_WALL`/`RIGHT_WALL` and it holds `TOF_WALL_FOLLOW_TARGET_MM` clearance.
Both walls out of range (>`TOF_WALL_SEEN_MAX_MM`) → `mode NONE`, no correction
(coasts on the IMU heading).

**Known issues & fixes**

| Symptom | Cause | Fix |
|---|---|---|
| Sits off-centre by a constant amount | ToF mounts not symmetric, or a per-sensor bias | trim in one place — `ToFArray` (`hardware/tof.py`) or add an offset; verify `left==right` when physically centred |
| Wanders / hunts side to side | gain too high or deadband too small | lower `TOF_CENTER_KP`, raise `TOF_CENTER_DEADBAND_MM`, cap with `TOF_CENTER_MAX_NUDGE_DEG` |
| Over-corrects at corners | far wall drops out mid-corner and it switches to wall-follow abruptly | tune `TOF_WALL_SEEN_MAX_MM` and `TOF_WALL_FOLLOW_TARGET_MM`; the corner marker + heading-hold handles the actual turn |
| Steers the wrong way | sign convention | +offset = displaced toward RIGHT wall = nudge left; locked by `testing/test_wall_centering.py` |
| Doesn't hug the inner wall in OPEN | `INNER_WALL_BIAS_MM` too small, or direction not yet latched | raise it; bias only applies once `race_direction` is known and only in BOTH-walls mode |
| L/R swapped (steers into walls) | ToF wiring — `tof1`=left/`tof2`=right assumption wrong | flip in one place, `ToFArray` in `hardware/tof.py` (its docstring calls this out) |

---

## Job 6 — Integration / state gating

```bash
python -m testing.camera.integration_test     # no hardware
```

Proves the glue in `runtime.py` around the detectors:

* each corner has 2 lines (entry + exit); runtime fires on each line's
  **appearance** and pairs them — the entry line enters the corner
  (→LAP_CHECK), the exit line completes it (→count). So a corner is counted
  **once**, on the exit line; `CORNERS_PER_LAP` (4) corners = 8 lines = 1 lap;
  `TARGET_LAPS` (3) = 24 lines = `THREE_LAPS_COMPLETE` once;
* run direction latches from the **first line's** colour (the entry line);
* the **OPEN** verdict fires after a full lap with no pillar;
* `run_pillars` is off in an OPEN run;
* `_VISION_ACTIVE_STATES` is exactly the 4 driving states (checked against the
  real `runtime` tuple when its deps import; else against the contract).

Expect `INTEGRATION: PASS`.

### On-robot end-to-end (the hardware half of Job 6)

This can only be signed off on the robot, with the ESP32 connected:

1. Put the car in a corridor, one red pillar ahead. Start a run (`main.py
   --mode run`, or the dashboard).
2. Watch the logs / dashboard: `PILLAR_DETECTED_RED` → state `AVOID_OBSTACLE`
   → a steer command on the serial wire (confirm the servo actually moves the
   right way) → pass the pillar → `OBSTACLE_CLEARED` → back to `FOLLOW_TRACK`.
3. Drive a full lap: 4 corners → `Lap complete: 1/3`. Three laps →
   `THREE_LAPS_COMPLETE` → PARK/STOP.
4. Repeat once with a **green** pillar (passes on the other side) and once with
   an **OPEN** mat (no pillars) to confirm mode auto-detection.

If a step here misbehaves but every `--selfcheck` above is green, the bug is in
the wiring (`runtime.py`), the serial link, or the firmware — **not** in the
camera/perception code you just isolated.

---

## Calibration tools

Run these whenever you change venue/lighting — the config defaults explicitly
say they need an on-mat pass.

**Colour bounds** — repeat per colour, paste the suggested lines into
`config/camera_config.py` (or `thresholds.py` for `BLACK`):
```bash
python -m testing.camera.calibrate_hsv --color RED
python -m testing.camera.calibrate_hsv --color GREEN
python -m testing.camera.calibrate_hsv --color ORANGE
python -m testing.camera.calibrate_hsv --color BLUE
python -m testing.camera.calibrate_hsv --color MAGENTA
```
(No `BLACK`/wall calibration — walls are sensed by the side ToFs now, not the
camera; tune those via the `TOF_*` constants in `config/thresholds.py`.)
Fill the drawn centre box with one clean sample; it averages ~40 frames and
prints ready-to-paste bounds plus a preview so you can confirm the box sat on
the colour.

**Pillar distance focal length** — put a pillar at a tape-measured distance:
```bash
python -m testing.camera.calibrate_focal --distance-mm 1000
```
Paste the printed `CAMERA_FOCAL_PX` into `config/camera_config.py`, then re-run
`pillar_test` and confirm `~mm` matches your tape at 2–3 distances.

---

## Exhaustive sign-off checklist

A perfect camera = every box below ticked, in order. `[S]` = covered by
`--selfcheck` (logic), `[L]` = must be verified live/in-person, `[C]` =
calibration step.

### 0. Calibration (do first, on the competition mat)
- [ ] `[C]` HSV bounds calibrated for RED, GREEN, ORANGE, BLUE, MAGENTA under match lighting
- [ ] `[C]` `CAMERA_FOCAL_PX` calibrated against a tape-measured pillar
- [ ] `[C]` ToF centering tuned on the mat (`TOF_CENTER_KP`, `TOF_CENTER_DEADBAND_MM`, `TOF_WALL_FOLLOW_TARGET_MM`); left==right ToF when physically centred

### 1. Frame acquisition
- [ ] `[L]` Backend is `picamera2` on the Pi (not opencv/synthetic)
- [ ] `[S]` `[L]` Frame shape is `(240, 320, 3)`
- [ ] `[L]` Measured FPS ≈ 15
- [ ] `[L]` RGB order correct — pure-red object → R channel dominant, no pink cast
- [ ] `[S]` `[L]` `get_jpeg()` returns valid JPEG; dashboard MJPEG feed live
- [ ] `[S]` No-camera fallback degrades to synthetic without crashing

### 2. Pillar detection & avoidance
- [ ] `[S]` `[L]` Presence: pillar → blob; empty frame → none
- [ ] `[S]` Sub-`MIN_PILLAR_AREA` blob ignored; `[L]` tune the trigger distance
- [ ] `[L]` RED classified RED, GREEN classified GREEN under match lighting
- [ ] `[S]` Pass-side: RED→RIGHT, GREEN→LEFT
- [ ] `[S]` `[L]` Steer sign correct + `18° ≤ |steer| ≤ 60°` swept across frame
- [ ] `[S]` Distance trend correct; `[C]`/`[L]` absolute value matches tape
- [ ] `[S]` `new_detection` fires exactly once per appearance
- [ ] `[S]` `[L]` `cleared` fires via shrink+close AND via 5 lost frames
- [ ] `[S]` Single dropped frame does NOT clear (hysteresis)

### 3. Corner markers → laps (2 lines per corner: entry + exit)
- [ ] `[S]` `[L]` Orange vs blue classified correctly
- [ ] `[S]` Sub-`MIN_CORNER_MARKER_AREA` noise ignored; thin line still triggers
- [ ] `[S]` `[L]` One `new_detection` per line appearance; 4-frame hysteresis
- [ ] `[S]` Runtime fires on line **appearance** only (a single line ≠ a whole corner)
- [ ] `[S]` Lap math: 2 lines = 1 corner, 8 lines = 1 lap, **24 lines = 3 laps** → `THREE_LAPS_COMPLETE` once
- [ ] `[S]` `[L]` Direction latches from the **first line** (entry: orange=CW / blue=CCW), sticky
- [ ] `[L]` On robot: drive a full lap, confirm `Lap complete: 1/3` after 8 lines (not 4)

### 4. Parking zone
- [ ] `[S]` `[L]` Magenta detected; `MIN_PARKING_MARKER_AREA` respected
- [ ] `[S]` `[L]` 5 consecutive → confirm once, then latched
- [ ] `[S]` `[L]` <5-frame flash does NOT confirm

### 5. Corridor centering — ToF + IMU (`planning/wall_centering.py`, NOT the camera)
- [ ] `[S]` Both walls seen → `BOTH` mode; displaced right → nudge left (sign) — `testing/test_wall_centering.py`
- [ ] `[S]` One wall seen → `LEFT_WALL`/`RIGHT_WALL` wall-follow at `TOF_WALL_FOLLOW_TARGET_MM`
- [ ] `[S]` No walls in range → `NONE`, no nudge (coast on IMU heading)
- [ ] `[S]` Centred within deadband → no nudge; nudge clamped to `TOF_CENTER_MAX_NUDGE_DEG`
- [ ] `[S]` OPEN inner-wall bias (`INNER_WALL_BIAS_MM`) hugs the correct wall; OBSTACLE run unbiased
- [ ] `[L]` On robot: `left==right` ToF when physically centred (mount symmetry)
- [ ] `[L]` On robot: slide toward right wall → `offset_mm` positive, steers left back to centre
- [ ] `[L]` On robot: ToF L/R not swapped (car steers away from the near wall, not into it)

### 6. Integration / state gating
- [ ] `[S]` Vision runs only in the 4 driving states (no stray event in `WAIT_FOR_START`)
- [ ] `[S]` OPEN run gates pillar detection off; lane centering keeps running
- [ ] `[L]` End-to-end: pillar → `AVOID_OBSTACLE` → steer on the wire → cleared → `FOLLOW_TRACK`
- [ ] `[L]` Full OBSTACLE run and full OPEN run both finish correctly on the robot

When every box is ticked, the camera is done.

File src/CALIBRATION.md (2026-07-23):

# Hermes On-Mat Calibration & Tuning Guide

Everything in this guide is a **constant in `src/config/`** — no logic changes
needed. Tune in roughly the order below; each section says which file to edit,
what the symptom of a bad value looks like, and how to find a good one. Bring a
tape measure, the real mat, and a charged battery (gains that work at 8.4 V
drift as the pack sags).

> The defaults shipped in the repo are deliberately **conservative** (slower,
> wider margins) so the first runs fail safe rather than into a wall. Expect to
> make the car faster/tighter once each subsystem is trusted.

---

## 0. Before you tune anything

- Install perception deps on the Pi: `pip install opencv-python numpy pillow`
  (without `opencv-python`, every detector logs a warning and no-ops — the car
  will drive blind).
- Flash `firmware/esp_controller/` to the ESP32, then confirm the servo
  centre/limits and IMU sign (Sections 1–2) **before** trusting any autonomy.
- Sanity-check the wiring convention: `hardware/tof.py` and `firmware/.../tof.cpp`
  both assume **tof1 = LEFT, tof2 = RIGHT**. If a hand near the left sensor
  moves the *right* number on the dashboard, swap the sensors or flip the
  mapping in one place.

---

## 1. Servo centre & steering limits  → `firmware/esp_controller/config.h`

| Constant | Meaning | How to set |
|---|---|---|
| `SERVO_CENTER` | duty that points the wheels straight | Command `STEER,0`; adjust until the car rolls dead straight over 2 m. |
| `SERVO_LEFT` / `SERVO_RIGHT` | full-lock duties | Command ±90; set so the wheels hit mechanical max **without buzzing/stalling** the servo. |

Mirror the same physical straight-ahead in `robot_config.py:STEER_CENTER_DEGREE`
if you change the mechanical trim.

## 2. IMU heading sign  → `firmware/esp_controller/config.h`

`IMU_GZ_SIGN` must make a **clockwise (rightward) spin produce an increasing
heading**. Spin the chassis right by hand and watch `heading_deg` on the
dashboard; if it *decreases*, set `IMU_GZ_SIGN = -1`. Everything downstream
(`+steer = right`) depends on this being correct.

## 3. Heading-hold PID  → `config/pid_config.py`

This is the loop that keeps the car straight and executes avoidance turns.

- `STEER_PID_KP` (1.6): raise until the car corrects drift briskly; back off if
  it visibly weaves (oscillates) down a straight.
- `STEER_PID_KD` (0.35): raise to damp that weave.
- `STEER_PID_KI` (0.02): keep small; only for steady-state pull. Too high →
  slow snaking.
- `STEER_SLEW_MAX_DEG_PER_TICK` (12): lower for smoother, slower servo motion;
  raise if avoidance turns feel sluggish.

**Test:** drive a straight at speed — it should track arrow-straight. Then a
gentle S — it should settle without hunting.

## 4. Camera & colour thresholds  → `config/camera_config.py`

Use `testing/vision/pillar_vision_test.py` on the Pi, under **competition
lighting**, to read HSV values off the actual pillars/markers.

| Constants | Symptom if wrong |
|---|---|
| `HSV_RED_*`, `HSV_GREEN_*` | pillars missed, or mat/lighting misclassified as a pillar |
| `HSV_ORANGE_*`, `HSV_BLUE_*` | corners miscounted → laps wrong, wrong direction latched |
| `HSV_MAGENTA_*` | parking lot never confirmed (obstacle run won't park) |
| `MIN_PILLAR_AREA`, `MIN_CORNER_MARKER_AREA`, `MIN_PARKING_MARKER_AREA` | too low = noise triggers detections; too high = real markers ignored |

The four corner/pillar hue bands are chosen **not to overlap** — keep that gap
if you retune (see the comment block in the file).

## 5. Monocular distance / focal length  → `config/camera_config.py`

`CAMERA_FOCAL_PX` (350) sets the pillar distance estimate
`distance ≈ real_width × focal / pixel_width`. Calibrate: place a pillar at a
known distance (say 1000 mm), read its pixel width from the vision tester, solve
`focal = distance × pixel_width / PILLAR_REAL_DIAMETER_MM`. Then tune
`PILLAR_CLEAR_DISTANCE_MM` (180) so `OBSTACLE_CLEARED` fires just as you draw
alongside the pillar — too early aborts the pass, too late clips it.

## 6. Corridor centering — ToF + IMU  → `config/thresholds.py`

Centering is done from the two side ToFs, not the camera (see
`planning/wall_centering.py`). First make sure `left == right` ToF when the car
is physically centred in the corridor — if not, the mounts are asymmetric; fix
that before tuning gains.

- `TOF_WALL_SEEN_MAX_MM` (1200): a side reading at/above this is "no wall this
  side" (corner opening / wide corridor). Must exceed the widest the far wall
  sits at when the car is hard against the near wall.
- `TOF_CENTER_KP` (0.05) / `TOF_CENTER_MAX_NUDGE_DEG` (4): how hard the ToF
  difference drags the heading target toward centre. Raise KP if centering is
  lazy; lower it (or widen the deadband) if the car hunts side to side.
- `TOF_CENTER_DEADBAND_MM` (20): lateral offset treated as "centred enough".
- `TOF_WALL_FOLLOW_TARGET_MM` (500): clearance held to the single visible wall
  at corners / open edges. ~Half the corridor width.
- `INNER_WALL_BIAS_MM` (120): OPEN-only — mm to hug the inner wall once the run
  direction is known. 0 disables. Verify with `testing/test_wall_centering.py`.

## 7. ToF wall safety & speed  → `config/thresholds.py`

- `TOF_WALL_WARNING_MM` (150) / `TOF_WALL_CRITICAL_MM` (80): distances at which
  the car softens avoidance and slows. Widen if it clips walls, tighten if it's
  needlessly timid in the 1000 mm obstacle corridor.
- `SPEED_SCALE_WALL_WARNING/CRITICAL`, `SPEED_SCALE_MIN`: how much it slows near
  walls (fraction of base speed).
- Base speeds live in `robot_config.py`: `SPEED_DEFAULT_FORWARD` (150) is the
  main speed knob — raise for a faster run once everything else is trusted.

## 8. Inner-wall bias (OPEN only)  → `config/thresholds.py`

`INNER_WALL_BIAS_MM` (120) shifts the open-challenge racing line toward the inner
wall once direction is known. **0 disables it** (pure centering). Increase for a
tighter line; back off if the car ever brushes the inner wall. Never applied in
an obstacle run.

## 9. Challenge separation & finish  → `config/thresholds.py`

- `OPEN_DECISION_AFTER_CORNERS` (4 = one lap): how long to wait, pillar-free,
  before committing to "this is the Open Challenge." Leave at one lap unless
  obstacle-run pillars appear later than that on your field.
- `START_MOVE_DELAY_S` (0.75): pause after the button so the starter can step
  back. Set `0.0` to launch instantly.
- `FINAL_APPROACH_OPEN_DURATION_S` (1.2): how long the car drives past the
  finish line before stopping on an open run. Tune so it halts **just inside**
  the start section. (Time-based — there is no encoder on this platform.)

## 10. Parallel parking  → `config/parking_config.py`

Tune **durations first**, they dominate. Chalk the spot, run `PARK` repeatedly
(you can force it on the bench by injecting `PARKING_ZONE_DETECTED`).

1. `PARK_SIDE_*` / `PARK_SIDE_OVERRIDE`: confirm the car turns toward the lot.
   If it reverses away from the spot, flip `PARK_SIDE_OVERRIDE`.
2. `PARK_REVERSE_IN_S` (1.30): long enough to swing the tail fully into the
   spot, not so long it hits the far wall.
3. `PARK_REVERSE_STRAIGHTEN_S` (1.20): brings the body parallel to the wall.
4. `PARK_FORWARD_SETTLE_S` (0.45): small nudge off the rear wall.
5. `PARK_STEER_DEG` (70): near full lock — raise for a tighter rotation.
6. Heading guards (`PARK_TURN_IN_DEG`, `PARK_ALIGN_TOLERANCE_DEG`): let the IMU
   end a stage early when the car has rotated/re-aligned enough. Set
   `PARK_USE_HEADING_GUARD = False` to fall back to pure timing if the IMU is
   noisy in the spot.
7. `PARK_MIN_SIDE_CLEARANCE_MM` (60): rear-wall ToF safety cut-off; `0` disables.

---

## Quick reference: the "make it faster" knobs

Once every subsystem above is trusted, these are the levers for a faster run,
in order of impact: `SPEED_DEFAULT_FORWARD` ↑, `SPEED_SCALE_*` ↑ (less braking
near walls), `STEER_SLEW_MAX_DEG_PER_TICK` ↑ (snappier turns),
`START_MOVE_DELAY_S` → 0. Raise one at a time and re-run.

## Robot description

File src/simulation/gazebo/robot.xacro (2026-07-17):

<?xml version="1.0"?>
<robot xmlns:xacro="http://www.ros.org/wiki/xacro" name="hermes_bot">

  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
  <link name="base_footprint"/>
  <link name="base_link">
    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
    <inertial><mass value="0.5"/>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</inertial>
  </link>
  <joint name="base_joint" type="fixed"><parent link="base_footprint"/><child link="base_link"/><origin xyz="0 0 0.05" rpy="0 0 0"/></joint>

  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
  <link name="rear_left_wheel">
    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
    <inertial><mass value="0.1"/>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</inertial>
  </link>
  <joint name="rear_left_joint" type="continuous"><parent link="base_link"/><child link="rear_left_wheel"/><origin xyz="-0.08 0.1 -0.01" rpy="1.5708 0 0"/><axis xyz="0 0 1"/></joint>

  <link name="rear_right_wheel">
    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
    <inertial><mass value="0.1"/>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</inertial>
  </link>
  <joint name="rear_right_joint" type="continuous"><parent link="base_link"/><child link="rear_right_wheel"/><origin xyz="-0.08 -0.1 -0.01" rpy="1.5708 0 0"/><axis xyz="0 0 1"/></joint>

  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
  <link name="front_left_steer_hinge">
    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
    <inertial><mass value="0.05"/>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</inertial>
  </link>
  <joint name="front_left_steer_joint" type="revolute"><parent link="base_link"/><child link="front_left_steer_hinge"/><origin xyz="0.1 0.08 -0.01"/><axis xyz="0 0 1"/><limit lower="-0.5" upper="0.5" effort="10" velocity="1.0"/></joint>

  <link name="front_left_wheel">
    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
    <inertial><mass value="0.1"/>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</inertial>
  </link>
  <joint name="front_left_wheel_joint" type="continuous"><parent link="front_left_steer_hinge"/><child link="front_left_wheel"/><origin xyz="0 0.02 0" rpy="1.5708 0 0"/><axis xyz="0 0 1"/></joint>

  <link name="front_right_steer_hinge">
    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
    <inertial><mass value="0.05"/>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</inertial>
  </link>
  <joint name="front_right_steer_joint" type="revolute"><parent link="base_link"/><child link="front_right_steer_hinge"/><origin xyz="0.1 -0.08 -0.01"/><axis xyz="0 0 1"/><limit lower="-0.5" upper="0.5" effort="10" velocity="1.0"/></joint>

  <link name="front_right_wheel">
    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
    <inertial><mass value="0.1"/>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</inertial>
  </link>
  <joint name="front_right_wheel_joint" type="continuous"><parent link="front_right_steer_hinge"/><child link="front_right_wheel"/><origin xyz="0 -0.02 0" rpy="1.5708 0 0"/><axis xyz="0 0 1"/></joint>

  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
  <link name="tof_front">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</link>
  <joint name="tof_front_j" type="fixed"><parent link="base_link"/><child link="tof_front"/><origin xyz="0.125 0 0.02"/></joint>

  <link name="tof_left">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</link>
  <joint name="tof_left_j" type="fixed"><parent link="base_link"/><child link="tof_left"/><origin xyz="0.05 0.08 0.02" rpy="0 0 1.5708"/></joint>

  <link name="tof_right">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</link>
  <joint name="tof_right_j" type="fixed"><parent link="base_link"/><child link="tof_right"/><origin xyz="0.05 -0.08 0.02" rpy="0 0 -1.5708"/></joint>

  <link name="camera_link">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</link>
  <joint name="camera_j" type="fixed"><parent link="base_link"/><child link="camera_link"/><origin xyz="0.12 0 0.04"/></joint>

  <link name="imu_link">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</link>
  <joint name="imu_j" type="fixed"><parent link="base_link"/><child link="imu_link"/><origin xyz="0 0 0.025"/></joint>

  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
  <link name="pi_link">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</link>
  <joint name="pi_j" type="fixed"><parent link="base_link"/><child link="pi_link"/><origin xyz="0.02 0 0.045"/></joint>

  <link name="power_block">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<inertial><mass value="0.4"/>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</inertial></link>
  <joint name="power_j" type="fixed"><parent link="base_link"/><child link="power_block"/><origin xyz="-0.06 0 0.035"/></joint>

  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

</robot>

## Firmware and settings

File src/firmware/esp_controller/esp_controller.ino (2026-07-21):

#include "serial_protocol.h"
#include "config.h"
#include "motor.h"
#include "servo_control.h"
#include "imu.h"
#include "tof.h"
#include "start_button.h"

namespace
{
    RobotCommand activeCommand;

    int speedToMotorDuty(const RobotCommand &command)
    {
        int speed = constrain(command.speed, 0, 255);
        return map(speed, 0, 255, 0, 100);
    }

    void applyCommand(const RobotCommand &command)
    {
        // Motor: STOP (and any non-drive action) means "don't drive"; only
        // FORWARD/BACKWARD move the wheels. Steering is handled AFTER this,
        // unconditionally, so it applies to STOP too (see below).
        if (command.action == "STOP")
        {
            setMotorSpeed(0);
        }
        else
        {
            int motorSpeed = speedToMotorDuty(command);
            if (command.action == "BACKWARD")
            {
                motorSpeed = -motorSpeed;
            }
            else if (command.action != "FORWARD")
            {
                motorSpeed = 0;
            }
            setMotorSpeed(motorSpeed);
        }

        // Steering runs for EVERY action, STOP included. The Pi sends a real
        // steer value alongside a STOP when the operator holds a/d without a
        // drive key ("pre-aim the wheels before moving" -- see the Pi's
        // hardware/buttons.py get_manual_target). Forcing SERVO_CENTER on STOP
        // here would throw that away and the wheels would never turn until a
        // drive key was also held. (Emergency stop still hard-centers via the
        // emergencyActive() branch in loop(), which does not call this.)
        //
        // NOTE: this is the ONE place a steer value crosses from the wire
        // protocol into the physical servo. Whatever the Pi sent -- whether
        // that's raw manual input or the output of the IMU heading-hold PID
        // (control/steering_control.py) -- lands here identically.
        //
        // The Pi sends an abstract steer in [-90, +90] (+ = right, - = left);
        // we map it to physical servo degrees. Mapping is PIECEWISE around
        // SERVO_CENTER instead of a single map(LEFT..RIGHT) because the
        // steering geometry is asymmetric (SERVO_CENTER is NOT the midpoint of
        // SERVO_LEFT/SERVO_RIGHT). A single linear map would put steer=0 at the
        // midpoint, biasing "straight ahead" off the calibrated center; the
        // split makes steer=0 land exactly on SERVO_CENTER and lets each side
        // use its own travel.
        int steerCmd = constrain(command.steer, -90, 90);
        int servoAngle = (steerCmd <= 0)
            ? map(steerCmd, -90, 0, SERVO_LEFT, SERVO_CENTER)
            : map(steerCmd,   0, 90, SERVO_CENTER, SERVO_RIGHT);
        setSteeringAngle(servoAngle);
    }
}

void setup() {
    initSerial();
    // Servo BEFORE motor: initServo() reserves its own LEDC timer (see
    // servo_control.cpp) so the motor's ledcAttach() can't share/reconfigure
    // the timer driving the 50 Hz servo frame and skew its center.
    initServo();
    initMotor();
    initStartButton();
    initIMU(); // failure is non-fatal: readIMU() falls back to level/stationary
               // defaults and the STATUS,ERR line already told the Pi why.
    initTOF(); // same deal: non-fatal, readTOF() holds 0.0 for any sensor
               // that failed to come up and the STATUS,ERR line says which.

    activeCommand.valid = true;
    applyCommand(activeCommand);
}

void loop() {
    processSerial();
    updateStartButton();

    if (commandAvailable()) {
        activeCommand = getLatestCommand();
    }

    if (emergencyActive()) {
        setMotorSpeed(0);
        setSteeringAngle(SERVO_CENTER);
        clearEmergency();
    }
    else if (activeCommand.valid) {
        applyCommand(activeCommand);
    }

    updateMotor();
    updateServo();

    // Telemetry on a fixed cadence (TELEMETRY_INTERVAL) rather than every loop.
    // Command handling above still runs at full loop speed for responsiveness;
    // only the sensor read + TEL send are rate-limited, so the TEL line paces
    // itself instead of saturating the serial link.
    static unsigned long lastTelemetryMs = 0;
    unsigned long nowMs = millis();
    if (nowMs - lastTelemetryMs >= TELEMETRY_INTERVAL) {
        lastTelemetryMs = nowMs;

        RobotTelemetry telemetry;
        readIMU(telemetry); // fills ax..gz
        readTOF(telemetry); // fills tof1_mm (left) / tof2_mm (right)
        sendTelemetry(telemetry);
    }
}

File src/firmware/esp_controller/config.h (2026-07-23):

#pragma once

// I2C Configuration
const int IMU_I2C_ADDRESS = 0x6A;
//const int TOF_I2C_ADDRESS = 0x7E;
const int I2C_SDA_PIN = 21;
const int I2C_SCL_PIN = 22;

const int IMU_SAMPLE_RATE_HZ = 104;

// ---- ToF (VL53L1X x2) ------------------------------------------------
// VL53L1X boots at a fixed default address (0x29) with no way to strap a
// different one in hardware, so two on one bus need the standard XSHUT
// dance: hold both in reset, bring the LEFT sensor up alone and re-address
// it off 0x29, THEN bring the RIGHT sensor up (which is free to stay at
// the now-vacated default). See firmware/esp_controller/tof.cpp.
//
// Pins match the known-good dual-sensor bench test
// (testing/firmware/tof_test/tof_test.ino): the sensor brought up FIRST and
// re-addressed to 0x30 is on GPIO34 (== LEFT here), and the one that stays at
// the 0x29 default is on GPIO32 (== RIGHT). NOTE: GPIO34 is input-only, but
// that's fine for LEFT specifically -- it's powered up first and never has to
// be held OFF while another sensor sits at 0x29 (RIGHT, on the output-capable
// GPIO32, is the one held in reset during LEFT's re-addressing). Do NOT put the
// RIGHT sensor on an input-only pin -- it must actually be driven low.
const int PIN_TOF_LEFT_XSHUT = 34;   // -> 0x30, brought up first (input-only ok, see above)
const int PIN_TOF_RIGHT_XSHUT = 32;  // -> 0x29, must be output-capable (held in reset first)
const int TOF_DEFAULT_I2C_ADDRESS = 0x29;   // VL53L1X power-on default
const int TOF_LEFT_I2C_ADDRESS = 0x30;      // re-addressed at boot, see tof.cpp
const int TOF_RIGHT_I2C_ADDRESS = TOF_DEFAULT_I2C_ADDRESS;

// Documents the sensor's expected ranging cycle time; not written to the
// sensor directly (kept out of the timing-budget API to avoid depending on
// a specific Pololu VL53L1X library version) -- it just explains why
// TELEMETRY_INTERVAL below isn't tighter than this.
const int TOF_TIMING_BUDGET_MS = 20;

// Motor pins
const int PIN_MOTOR_IN1 = 18;
const int PIN_MOTOR_IN2 = 25;
const int PIN_MOTOR_PWM = 23;  // ena

const int MOTOR_PWM_CHANNEL = 0; // unused in 3.0, apparently ledcAttach() uses the pin number directly now
const int MOTOR_PWM_FREQ = 1000;
const int MOTOR_PWM_RESOLUTION = 8;

// Steering servo
const int PIN_STEERING_SERVO = 14;
const int SERVO_CENTER = 158;
const int SERVO_LEFT = 180;
const int SERVO_RIGHT = 120;

// Start button
const int PIN_START_BUTTON = 2;

// LED (status indicator). MOVED off GPIO25 -- that pin is now PIN_MOTOR_IN2
// (see above). GPIO26 is free. (The LED isn't driven anywhere in the firmware
// yet, so this is just avoiding a duplicate-pin footgun for when it is.)
const int PIN_LED = 26;

// serial
const int long BAUD_RATE = 115200;
// Debug: echo each ACCEPTED CMD back over serial so you can confirm on the
// monitor that the ESP is actually receiving valid commands. A valid CMD is
// otherwise silent (see handleCmd in serial_protocol.cpp), which is why a good
// packet looks like "nothing happened". Set to 0 before racing: at the Pi's
// streaming rate this floods the serial TX and competes with the TEL line.
#define DEBUG_ECHO_CMD 1

    // Debug: echo each ACCEPTED CMD back over serial so you can confirm on the
    // monitor that the ESP is actually receiving valid commands. A valid CMD is
    // otherwise silent (see handleCmd in serial_protocol.cpp), which is why a good
    // packet looks like "nothing happened". Set to 0 before racing: at the Pi's
    // streaming rate this floods the serial TX and competes with the TEL line.
    #define DEBUG_ECHO_CMD 1

// telemetry
const unsigned long TELEMETRY_INTERVAL = 100;

// IMU mounting: flip this to -1 on the bench if a clockwise (rightward) spin
// of the chassis produces a DECREASING gz reading instead of increasing --
// the Pi integrates heading += gz*dt and expects +gz = turning right, to
// match the steer sign convention used everywhere else (+ = right).
const int IMU_GZ_SIGN = 1;

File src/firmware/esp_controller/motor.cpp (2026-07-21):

#include <Arduino.h>
#include <ESP32Servo.h>  // pulls in ESP32PWM

#include "motor.h"
#include "config.h"

// The ENA (speed) pin is driven through ESP32PWM -- the SAME LEDC wrapper the
// steering servo uses (servo_control.cpp / ESP32Servo). Previously this file
// used the core's raw ledcAttach()/ledcWrite() while the servo used ESP32Servo;
// the two allocate LEDC timers through different bookkeeping and were colliding,
// which left the ENA pin without a valid PWM signal -- so the motor sat dead in
// BOTH directions even though IN1/IN2 toggled correctly. Routing both PWMs
// through ESP32PWM with a dedicated timer each (servo = timer 0, reserved in
// initServo which runs first; motor = timer 1, reserved below) keeps them from
// ever sharing/reconfiguring the same timer.
namespace
{
    ESP32PWM motorPwm;
}

int currentMotorSpeed = 0;

void initMotor()
{
    pinMode(PIN_MOTOR_IN1, OUTPUT);
    pinMode(PIN_MOTOR_IN2, OUTPUT);

    // Reserve a timer distinct from the servo's (timer 0) and attach the ENA
    // pin at the motor's own frequency/resolution.
    ESP32PWM::allocateTimer(1);
    motorPwm.attachPin(PIN_MOTOR_PWM, MOTOR_PWM_FREQ, MOTOR_PWM_RESOLUTION);

    setMotorSpeed(0);
}

void setMotorSpeed(int speed)
{
    speed = constrain(speed, -100, 100);

    currentMotorSpeed = speed;

    if (speed > 0)
    {
        digitalWrite(PIN_MOTOR_IN1, HIGH);
        digitalWrite(PIN_MOTOR_IN2, LOW);
    }
    else if (speed < 0)
    {
        digitalWrite(PIN_MOTOR_IN1, LOW);
        digitalWrite(PIN_MOTOR_IN2, HIGH);
    }
    else
    {
        digitalWrite(PIN_MOTOR_IN1, LOW);
        digitalWrite(PIN_MOTOR_IN2, LOW);
    }

    // MOTOR_PWM_RESOLUTION is 8-bit, so duty range is 0..255.
    int duty = map(abs(speed), 0, 100, 0, 255);
    motorPwm.write(duty);
}

void updateMotor()
{
    // Reserved for acceleration limiting later.
}

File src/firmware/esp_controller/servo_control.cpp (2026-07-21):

#include <Arduino.h>
#include <ESP32Servo.h>

#include "config.h"
#include "servo_control.h"

// Drives the steering servo with the ESP32Servo library -- the SAME method as
// testing/firmware/servo_test/servo_test.ino, which is known to move the servo
// correctly on the bench.
//
// WHY NOT raw ledcAttach/ledcWrite (the previous approach): the main firmware
// also drives the motor PWM with its own ledcAttach() (motor.cpp, 1000 Hz /
// 8-bit), initialised BEFORE the servo. Standing up a second raw LEDC channel
// at a very different config (50 Hz / 16-bit) alongside it makes servo motion
// depend on how the two share the chip's four LEDC timers -- which is exactly
// why the servo moved in the standalone test (no motor LEDC present) but not in
// the full firmware. ESP32Servo manages its own timer allocation and coexists
// cleanly with the motor's channel, so the servo behaves identically to the
// isolated test.
namespace
{
    Servo steeringServo;
    int currentSteeringAngle = SERVO_CENTER;
}

void initServo()
{
    // Reserve a dedicated LEDC timer for the servo BEFORE attaching, so its
    // 50 Hz frame can't be disturbed by the motor's own ledcAttach() (1000 Hz)
    // sharing the same timer. A shared/reconfigured timer would skew the pulse
    // width the servo actually sees, which shows up as the physical center
    // sitting off from the calibrated SERVO_CENTER even though we write 158.
    // (esp_controller.ino setup() calls initServo() BEFORE initMotor() so this
    // reservation happens first.)
    ESP32PWM::allocateTimer(0);

    // Match the working bench test exactly: 50 Hz frame, 500-2500 us pulse.
    steeringServo.setPeriodHertz(50);
    steeringServo.attach(PIN_STEERING_SERVO, 500, 2500);
    setSteeringAngle(SERVO_CENTER);
}

void setSteeringAngle(int angleDegrees)
{
    // Clamp to the calibrated physical travel (SERVO_LEFT..SERVO_RIGHT in
    // either order) so a bad command can't drive the linkage into a hard stop.
    int minAngle = min(SERVO_LEFT, SERVO_RIGHT);
    int maxAngle = max(SERVO_LEFT, SERVO_RIGHT);

    currentSteeringAngle = constrain(angleDegrees, minAngle, maxAngle);

    steeringServo.write(currentSteeringAngle);
}

void updateServo()
{
    (void)currentSteeringAngle;
}

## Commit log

2026-05-10 feat: Add simulation code(Version 1)
    [robot.xacro]
2026-05-13 feat(simulation): add initial markdown files for simulation components - create .gitkeep in simulation directory - add gazebo.md for gazebo code - add algos.md for prototype algorithms - add camera.m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
2026-06-16 chore: setup central pin configuration and gitignore python caches
2026-06-16 eat: add Arduino Uno actuation firmware with safety watchdog
2026-06-16 feat(DriveCommand): add autonomous drive layer, robot context, and structured logging
    * Add RobotContext dataclass with lap count, state tracking, pillar color, obstacle/error flags, and reset logic
    * Add controlled RobotContext methods (increment_lap, update_state, set_error, clear_error) with integrated logging
    * Refactor all module loggers to use get_logger(__name__) for named, per-module log output
    * Add drive_command() in control/drive_command.py mapping each State to (speed, steer, action) tuple
    * Implement pillar-color-aware steering in AVOID_OBSTACLE (RED → left, GREEN → right)
    * Wire drive_command and StateMachine into run_realtime_loop, replacing autonomous placeholder
    * Add Ro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
2026-06-16 chore(StateMachine): enforce event priority spec, add INIT stubs and ERROR reset
    * Fix nested class bug in StateMachine.__init__ left from RobotContext integration
    * Add self.context = RobotContext() correctly to StateMachine.__init__
    * Call context.update_state() on every state transition in handle_event()
    * Add INIT system check stubs with TODO comments for camera, serial, PID, and sensor verification
    * Add StateMachine.reset() method to handle ERROR -> INIT manual recovery path
    * Add EVENT_PRIORITY_MAP in events.py as canonical priority source per competition spec
    * Add make_event() factory function to enforce spec-compliant priority on all Event construction
    * Refactor mock_events.py to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
2026-06-16 feat(EventQueue): implement priority-ordered thread-safe event queue
    * Add EventQueue in state_machine/event_queue.py using heapq min-heap with negated priority for max-heap behaviour
    * Enforce spec priority order: CRITICAL > HIGH > MEDIUM > LOW on every pop()
    * Preserve FIFO ordering within the same priority level using an arrival counter tiebreaker
    * Add thread-safe lock on all queue operations for safe use in the 20Hz real-time loop
    * Add peek(), drain(), clear(), size(), and is_empty() utility methods
    * clear() called on ERROR entry and reset() to flush stale events
    * Add test_event_queue.py with 9 unit tests covering priority ordering, FIFO, drain, clear, peek, and edge cases
2026-07-08 IMU, Motor, Servo Tets
2026-07-08 fix: duplicate parser in main fix
    [buttons.py]
2026-07-13 feat(communication, firmware): enhance serial communication protocol - implement parsing for CMD, EMG, PING, and ACK packets - add telemetry data handling in packet_parser.py - update SerialLink clas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
    [packet_parser.py, protocol.py, serial_link.py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]
2026-07-15 - sync imu variables - refactor serial_packet -> serial_command - firmware actuates from command
2026-07-15 feat(monitoring): hardware-in-the-loop sim, ground station, and full-path logging
    Adds a hardware-substitution layer, a monitoring/simulation web UI, richer
    manual driving, and end-to-end logging so the whole stack runs and is
    observable with no working hardware (ESP32-WROOM-32 + Raspberry Pi 4 target).
    Core spine — TelemetryHub (utils/telemetry_hub.py)
    In-process pub/sub with a latest-value snapshot and a rolling log buffer.
    Every subsystem publishes here; the file logger and the dashboard are just
    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
2026-07-16 Component-gallery done
    [MIDDLE LINKAGE alts.STEP, battery_holder.STEP, column 1.STEP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]
2026-07-16 refactor(preprocessing): consolidate pillar detection logic - remove redundant color masking and contour finding from detect_pillars - delegate detection logic to find_largest_pillar in pillar_detect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
    refactor(runtime): enhance runtime structure and event handling
    - introduce pillar_detector and steering_controller for modularity
    - implement vision pipeline updates in tick method
    - adjust state machine initialization to check camera and serial readiness
    refactor(state_machine): improve state management and reset logic
    - add parameters for camera and serial readiness in StateMachine
    - refine reset logic to handle hardware st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
    [config.h, diagnostics.py, esp_controller.ino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]
2026-07-16 working on the models foder
    [MIDDLE LINKAGE alts.STEP, bevel gear.STEP, column 1.STEP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]
2026-07-17 Add new CAD models and update README with new entries
2026-07-17 Fix key presses not registering issue
    [buttons.py]
2026-07-17 Esp <-> Pi communication protocol fix
    [esp_controller.ino, serial_protocol.cpp]
2026-07-17 chore(cleanup): Move simulation files into src/simulation/gazebo. Add simulation video to gazebo.md
    [robot.xacro]
2026-07-17 cleanup sim files
    [robot.xacro]
2026-07-18 fix: tests use synthetic jpeg array when no real camera is found
    [camera.py]
2026-07-18 fix: sim event clashing with scenario injection
    [config.h]
2026-07-18 fix: servo ledc constraint
    [servo_control.cpp]
2026-07-18 fix: servo steering raneg and config values
    [servo_control.cpp]
2026-07-21 chore: switched from adafruit to pololu
2026-07-21 camera inversion fix
2026-07-21 update i2c scanner
2026-07-21 feat: threading
2026-07-22 new tests, calibrations
2026-07-23 cmd not echoing fix
    [config.h, serial_protocol.cpp]
2026-07-23 motors not driving fix
    [config.h]
2026-07-23 threading fix 2.0
2026-07-23 camera tests
2026-07-23 fix: remove camera from lane centering algorithm
    [roi.py]
2026-07-23 fix: lap counting fix
    [corner_detection.py]
